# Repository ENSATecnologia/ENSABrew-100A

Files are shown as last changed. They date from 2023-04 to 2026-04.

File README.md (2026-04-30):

# ENSABrew-100A

## PT-BR

Projeto ENSA Tecnologia para controle de brassagem e producao, com firmware ATMEL/Arduino, protocolo serial e logger Node.js.

### Visao geral

O repositorio reune firmware, bibliotecas, protocolo, projeto mecanico, PCB e logger operacional para o equipamento ENSABrew-100A.

### Estrutura

| Caminho | Descricao |
| --- | --- |
| `ENSABrewFirmware/` | Firmware principal e variantes historicas |
| `ENSABrewLibraries/` | Bibliotecas compartilhadas |
| `LoggerBuffaloBrew/` | Logger operacional Node.js |
| `ENSABrewPCB/` | Arquivos de PCB |
| `ENSABrewMechanicalProject/` | Projeto mecanico |
| `Protocol/` e `ENSABrewProtocol/` | Documentacao de protocolo |

### Diretriz de manutencao

`ENSABrew/` e a base ativa de manutencao. `ENSABrewBuffaloBeer/` deve ser tratada como arvore legada/historica, mantida apenas para referencia e comparacao. Novas mudancas devem entrar em `ENSABrew/`, salvo necessidade explicita de suporte a essa variante antiga.

### Estado atual

- A recepcao serial foi corrigida para nao deixar interrupcoes desligadas ao final de um ciclo incompleto de leitura.
- O caminho principal de JSON foi reduzido para `StaticJsonDocument` em vez de `DynamicJsonDocument` nos fluxos mais importantes de serial, APP e resposta remota.
- As chaves de autenticacao e identificadores sensiveis foram movidos para configuracao persistida em EEPROM, com valores de bootstrap definidos no firmware.
- O protocolo serial agora documenta o tamanho maximo do pacote (`DATA_UTIL_SERIAL = 512`) e os campos principais esperados.
- O logger Node.js passou a lidar com framings por linha e limite de buffer, reduzindo erros de leitura parcial.
- As rotinas de display e relogio reduziram copias desnecessarias de `String` nos caminhos mais usados.
- A arvore `ENSABrewBuffaloBeer/` segue documentada como legado, para evitar manutencao dupla.

### Ajustes adicionais que ainda valem

- Reduzir o uso de `String` nas rotinas de receita e nas comparacoes de nome ainda espalhadas pelo firmware.
- Reduzir o uso restante de `String` nas telas de configuracao, edicao de receita e mensagens dinamicas do display.
- Tratar explicitamente pacote incompleto, pacote excedido e erro de autenticacao, sem depender de comportamento implcito do loop.
- Separar melhor codigo do projeto e dependencias vendorizadas, para facilitar manutencao e auditoria.
- Manter o contrato do protocolo centralizado no arquivo `Protocol/protocolo ENSABrew.md`.

### Observacao

Os pontos acima foram inferidos por leitura estatica do codigo e da documentacao, nao por teste em hardware.

### Licenca

Consulte `LICENSE`.

---

## English

ENSA Tecnologia project for brewing/production control, with ATMEL/Arduino firmware, serial protocol and Node.js logger.

### Overview

This repository gathers firmware, libraries, protocol, mechanical project, PCB and the operational logger for the ENSABrew-100A equipment.

### Structure

| Path | Description |
| --- | --- |
| `ENSABrewFirmware/` | Main firmware and historical variants |
| `ENSABrewLibraries/` | Shared libraries |
| `LoggerBuffaloBrew/` | Node.js operational logger |
| `ENSABrewPCB/` | PCB files |
| `ENSABrewMechanicalProject/` | Mechanical project |
| `Protocol/` and `ENSABrewProtocol/` | Protocol documentation |

### Maintenance direction

`ENSABrew/` is the active maintenance base. `ENSABrewBuffaloBeer/` should be treated as a legacy/historical tree, kept only for reference and comparison. New changes should land in `ENSABrew/` unless there is an explicit need to support that older variant.

### Current state

- Serial reception has been corrected so it no longer leaves interrupts disabled after an incomplete read cycle.
- The main JSON path has been reduced to `StaticJsonDocument` instead of `DynamicJsonDocument` in the main serial, APP and remote-reply flows.
- Authentication keys and sensitive identifiers were moved into persisted EEPROM-backed configuration, with firmware bootstrap defaults.
- The serial protocol now documents the maximum packet size (`DATA_UTIL_SERIAL = 512`) and the main expected fields.
- The Node.js logger now handles line-based framing and a bounded buffer to reduce partial-read errors.
- Display and clock routines now avoid unnecessary `String` copies in the most-used paths.
- The `ENSABrewBuffaloBeer/` tree remains documented as legacy to avoid maintaining two active code paths.

### Additional code improvements worth doing

- Reduce `String` usage in recipe routines and in the remaining name comparison helpers in the firmware.
- Reduce the remaining `String` usage in configuration screens, recipe editing and dynamic display messages.
- Handle incomplete packets, oversized packets and authentication failures explicitly instead of relying on loop behavior.
- Separate project code from vendored dependencies more clearly to simplify maintenance and auditability.
- Keep the protocol contract centralized in `Protocol/protocolo ENSABrew.md`.

### Note

The points above were inferred from static code and documentation review, not from hardware testing.

### License

See `LICENSE`.

### Auditoria / Audit
#### PT-BR
- O firmware ja melhorou bastante, mas ainda vale reduzir String restante nas telas, entradas e mensagens dinamicas.
- O contrato do protocolo serial precisa permanecer centralizado e coerente com o logger e o firmware ativo.
- Configuracoes persistidas, limites de buffer e estados legados devem continuar documentados em um unico lugar.
- A prioridade pratica agora e fechar o que ainda gera churn de heap e manter o caminho critico previsivel.
#### EN
- The firmware has improved a lot, but it is still worth reducing the remaining String usage in screens, inputs and dynamic messages.
- The serial protocol contract must stay centralized and aligned with the logger and the active firmware.
- Persisted configuration, buffer limits and legacy states should continue to be documented in one place.
- The practical priority now is to close the remaining heap churn and keep the critical path predictable.

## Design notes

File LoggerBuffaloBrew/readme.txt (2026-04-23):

-> Descrição do dado: (NOME DA RECEITA) | (RAMPA/SETPOINT) | (N° RAMPA/SETPOINT) | (TEMP. SENSOR) | (TEMP. SETPOINT) | (TEMPO ATUAL) | (ESTADO RELÉ)
	
	- (NOME DA RECEITA): Nome da receita atual;
	
	- (RAMPA/SETPOINT): Se refere a etapa em si, em qual delas está, ou RAMPA (subindo a temperatura) ou SETPOINT (contando tempo e mantendo a temperatura);
	
	- (N° RAMPA/SETPOINT): Se refere ao número/ID da RAMPA ou do SETPOINT, ambos serão os mesmos;

	- (TEMP. SENSOR): Temperatura atual do SENSOR;
	
	- (TEMP. SETPOINT): Temperatura atual do SETPOINT (será fixa na contagem de tempo);

	- (TEMPO ATUAL): tempo total do SETPOINT em questão (em minutos). Enquanto estiver em RAMPA, se mantém travado até chegar ao SETPOINT e chegando ao mesmo, faz uma contagem decrescente;

	- (ESTADO RELÉ): Estado atual do relé: (1) acionado | (0) desacionado

* OBSERVAÇÃO:
	
	-> Caso queira alterar a PORTA de conexão com o servidor, acesse o arquivo 'conectionPort.js' e altere diretamente o valor;

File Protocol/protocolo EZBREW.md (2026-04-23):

#### Cabeçalho padrão ENSA Tecnologia

	Cabeçalhos de equipamentos ENSA Tecnologia
		4E

	Cabeçalhos de segmento
		0001 - Postos de combustíveis
		0002 - Módulos IoT voltado ao condomínio

	Identificador de módulo
		ZZZZZZZZZ é 09 bytes, sendo [a-zA-Z0-9]

	Tipo do módulo
		D001 - Portas i/o Raspberry PI3
		D002 - Módulo 433Mhz TCP/IP v4
		D003 - Módulo 433Mhz TCP/IP v4 OFFLINE
		D004 - Módulo Wiegand TCP/IP v4
		D005 - Módulo Wiegand TCP/IP v4 OFFLINE
		D006 - Módulo de leitura de bombas 

#### * Observação: Protocolo baseado em Json

	  Exemplo - início do cabeçalho:

				{"header":"4E",
				 "product":"0002",
				 "type":"D002",
				 "id":"1020ABC01",
				 "typeCmd":"...",
				 "cmd":"...",...}

#### CC - Cabeçalho de comando

###### Faixa de cabeçalhos CC

| Nome | Tipo ("typeCmd") | Faixa ("cmd")|
|---|---|---|
| Conexão | CC 	 	 | 00 	 |
| Receitas | CC 	 	 | 01 à 04 |
| Teclado Virtual | CC 	 	 | 05 |
| Configurações | CC 	 	 | 06 à 09 |
| Funções administrativas| CC 	 	 | 0A à 0E |
 
###### Conexão
	
	00 - Subcabeçalho para confirmar a conexão:
      
	- Exemplo: do APP para o equipamento
     
			{"header":"4E",
			 "product":"0002",
			 "type":"D002",
			 "id":"1020ABC01",
			 "typeCmd":"CC",
			 "cmd":"00"}

	- Exemplo: do equipamento para o APP  
     
			{"header":"4E",
			 "product":"0002",
			 "type":"D002",
			 "id":"1020ABC01",
			 "typeCmd":"CC",
			 "cmd":"00",
			 "connection:":"ack"}

###### Receitas

	01 - Subcabeçalho para CRIAR uma receita:
     
	-Parâmetros:
     
		-> Nome da receita:                            
			
			"receita":["nome da receita"],
     
		-> Quantidade de patamares e suas temperaturas: (em °C)
			
			"tempPatamar":[50],
       
	*Obs: o número de patamares será definido de acordo com a quantidade de temperaturas que forem definidas dentro dos colchetes.
     
		-> Tempo dos patamares: (em minutos) 
			
			"minPatamar":[5],
          
	*Obs: a quantidade de tempo dentro dos colchetes deve corresponder à quantidade de patamares definidos anteriormente.
      
		-> Temperatura de fervura:  (em °C)
			
			"tempFervura":100,
      
		-> Tempo em fervura: (em minutos)
			
			"minFervura":3,
     
		-> Quantidade e nomes das adições:	  
			
			"nomeAdicao":["Nome adicao"],    
       
	*Obs: o número de adições será definido de acordo com a quantidade de nomes que forem definidos dentro dos colchetes.
     
		-> Quantidade de adição: (em gramas)
			
			"gramasAdicao":[100],
     
    *Obs: a quantidade de adição dentro dos colchetes deve corresponder àquantidade de adições definidos anteriormente.
     
		-> Tempo de cada adição: (em minutos)
			
			"minAdicao":[5],
     
    *Obs: a quantidade de tempo dentro dos colchetes deve corresponder àquantidade de adições definidos anteriormente.
     
		-> Quantidade e nome dos Whirpools: 
			
			"nomeWhirpool":["Nome do Whirpool"],
     
    *Obs: o número de whirpools será definido de acordo com a quantidade de nomes que forem definidos dentro dos colchetes.  
     
		-> Tempo em cada Whirpool: (em minutos)
			
			"minWhirpool":[10],
     
    *Obs: a quantidade de tempo dentro dos colchetes deve corresponder àquantidade de whirpools definidos anteriormente.
     
		-> Tempo de descanso: (em minutos)
			
			"minDescanso":30}
     
	- Exemplo:
     
			{"header":"4E",
			 "product":"0002",
			 "type":"D002",
			 "id":"1020ABC01",
			 "typeCmd":"CC",
			 "cmd":"01",
			 "receita":[1,"Receita Exemplo"],
			 "tempPatamar":[75],
			 "minPatamar":[15],
			 "tempFervura":150,
			 "minFervura":10,
			 "nomeAdicao":["Adicao Exemplo"],
			 "gramasAdicao":[500],
			 "minAdicao":[2],
			 "nomeWhirpool":["Whirpool Exemplo"],
			 "minWhirpool":[20],
			 "minDescanso":15}

--------------------------------------------------------------------------
	
	02 - Subcabeçalho para EDITAR uma receita:
	 
	*Obs: as regras de criação valem para edição.   
	  
	-Parâmetros:
     
		-> Nome e número da receita: 
			
			..."receita":[1, "nome da receita editado"],
	     
		-> Quantidade de patamares e suas temperaturas: (em °C)
		   	
		   	"tempPatamar":[25],
	      
		-> Tempo dos patamares: (em minutos)  
		   	
		   	"minPatamar":[10],
	          
		-> Temperatura de fervura:  (em °C)    
		   	
		   	"tempFervura":200,
	     
		-> Tempo em fervura: (em minutos)   
		   	
		   	"minFervura":5,
	     
		-> Quantidade e nomes das adições:  
		   	
		   	"nomeAdicao":["Nome adicao editado"],    
	     
		-> Quantidade de adição: (em gramas)
		   	
		   	"gramasAdicao":[250],
	     
		-> Tempo de cada adição: (em minutos)
		   	
		   	"minAdicao":[20],
	     
		-> Quantidade e nome dos Whirpools: 
		   	
		   	"nomeWhirpool":["Nome do Whirpool editado"],
	     
		-> Tempo em cada Whirpool: (em minutos)
		   	
		   	"minWhirpool":[9],
	     
		-> Tempo de descanso: (em minutos)
		   	
		   	"minDescanso":30}
     
	- Exemplo:
     
			{"header":"4E",
			 "product":"0002",
			 "type":"D002",
			 "id":"1020ABC01",
			 "typeCmd":"CC",
			 "cmd":"02",
			 "receita":[1,"Receita Exemplo"],
			 "tempPatamar":[25],
			 "minPatamar":[10],
			 "tempFervura":80,
			 "minFervura":8,
			 "nomeAdicao":["Adicao Exemplo"],
			 "gramasAdicao":[250],
			 "minAdicao":[5],
			 "nomeWhirpool":["Whirpool Exemplo"],
			 "minWhirpool":[12],
			 "minDescanso":25}

--------------------------------------------------------------------------
	
	03 - Subcabeçalho para APAGAR uma receita:
      
		- Necessário apenas o número da receita à ser apagada: 
			
			..."receita":[1, ""]}	
     
	- Exemplo:
     
			{"header":"4E",
			 "product":"0002",
			 "type":"D002",
			 "id":"1020ABC01",
			 "typeCmd":"CC",
			 "cmd":"03",
			 "receita":[1,""]}

--------------------------------------------------------------------------

	04 - Subcabeçalho para BRASSAR uma receita:
      
		- Necessário apenas o número da receita à ser brassada: 
			
			..."receita":[1, ""]}
     
	- Exemplo:
     
			{"header":"4E",
			 "product":"0002",
			 "type":"D002",
			 "id":"1020ABC01",
			 "typeCmd":"CC",
			 "cmd":"04",
			 "receita":[1,""]}	

###### Teclado Virtual

	05 - Subcabeçalho para uso do "teclado virtual":
      
	- As teclas são definidas por seus respectivos nomes:
     
		-> UP
		-> DOWN
		-> LEFT
		-> RIGHT
		-> ENTER
		-> ESC
     
    	- Necessário apenas o nome da tecla à ser "pressionada":
        
    		..."vKey":"UP"}
     
	- Exemplo:
     
			{"header":"4E",
			 "product":"0002",
			 "type":"D002",
			 "id":"1020ABC01",
			 "typeCmd":"CC",
			 "cmd":"05",
			 "vKey":"UP"}

###### Configurações

	06 - Subcabeçalho para configurar o máximo de patamares:
     
    	- Necessário apenas o máximo de patamares desejado:
     
			..."maxPatamar":"10"}
     
	- Exemplo:
     
			{"header":"4E",
			 "product":"0002",
			 "type":"D002",
			 "id":"1020ABC01",
			 "typeCmd":"CC",
			 "cmd":"06",
			 "maxPatamar":"10"}

--------------------------------------------------------------------------

	07 - Subcabeçalho para configurar os graus por minuto:
     
    	- Necessário apenas o grau por minuto desejado:
     
			..."grauPorMinuto":"1.5"}
     
	- Exemplo:
     
			{"header":"4E",
			 "product":"0002",
			 "type":"D002",
			 "id":"1020ABC01",
			 "typeCmd":"CC",
			 "cmd":"07",
			 "grauPorMinuto":"1.5"}

--------------------------------------------------------------------------

	08 - Subcabeçalho para configurar o PWM para Setpoint:
     
    	- Necessário apenas o PWM desejado:
     
			..."setPWM":"75"}
     
	- Exemplo:
     
			{"header":"4E",
			 "product":"0002",
			 "type":"D002",
			 "id":"1020ABC01",
			 "typeCmd":"CC",
			 "cmd":"08",
			 "setPWM":"75"}

--------------------------------------------------------------------------

	09 - Subcabeçalho para configurar Data e Hora:
     
    	- Configurar os segundos:
     
			..."segundos":"00",
     
    	- Configurar os minutos:
     
			"minutos":"30",
     
    	- Configurar as horas:
     
			"horas":"09",
     
    	- Configurar o dia da semana: 
      
    	(1-SEG)(2-TER)(3-QUA)(4-QUI)(5-SEX)(6-SAB)(7-DOM)
     
			"diaDaSemana":"2",	
     
    	- Configurar o dia do mês:
     
			"diaDoMes":"15",
     
    	- Configurar o mês:
     
			"mes":"01",
     
    	- Configurar o ano:
     
			"ano":"2019"}
        
	- Exemplo:
     
			{"header":"4E",
			 "product":"0002",
			 "type":"D002",
			 "id":"1020ABC01",
			 "typeCmd":"CC",
			 "cmd":"05",
			 "segundos":"00",
			 "minutos":"30",
			 "horas":"09",
			 "diaDaSemana":"2",	
			 "diaDoMes":"15",
			 "mes":"01",
			 "ano":"2019"}

	--------------------------------------------------------------------------

	10 - Subcabeçalho para configurar o PID:
     
    	- Configurar o status: 00 - desabilitado | 01 - habilitado
     
			..."status":"01",
     
    	- Configurar kp:
     
			"kp":"1.5",
     
    	- Configurar ki:
     
			"ki":"2.5",
     
    	- Configurar kd:
     
			"kd":"3.5",
        
	- Exemplo:
     
			{"header":"4E",
			 "product":"0002",
			 "type":"D002",
			 "id":"1020ABC01",
			 "typeCmd":"CC",
			 "cmd":"10",
			 "status":"01",
			 "kp":"1.5",
			 "ki":"2.5",
			 "kd":"3.5"}

###### Funções Administrativas

	0A - Subcabeçalho para limpar a EEPROM:
     
    	- Necessário apenas o comando:
       
    		..."cmd":"0A"} 
     
	- Exemplo:
     
			{"header":"4E",
			 "product":"0002",
			 "type":"D002",
			 "id":"1020ABC01",
			 "typeCmd":"CC",
			 "cmd":"0A"}

	0B - Subcabeçalho para alterar o tempo de envio de dados da brassagem:
     
    - Necessário apenas o tempo (em segundos) desejado:
     
			..."setTime":"1"}
       
	- Exemplo:
     
			{"header":"4E",
			 "product":"0002",
			 "type":"D002",
			 "id":"1020ABC01",
			 "typeCmd":"CC",
			 "cmd":"0B",
			 "setTime":"5"}

	0C - Controle dos solenóides
     
    - Necessário definir o solenóide em que será feito o controle (1 (00) ou 2 (01))
     
			..."solenoid":"00"} 

	- Necessário definir a ação - acionar (01) ou desacionar (00)
     
			..."action":"01"}      

    - Necessário definir o tempo:
     
			..."operatingTime":"10"}

	- Necessário definir o tipo do temporizador (mili segundos (00), segundos (01) ou minutos (02)):
     
			..."timerType":"01"}

	*OBS: para acionamento sem temporização, colocar 0 em ambos campos acima

	- Exemplo: acionar o solenóide 1 por 10 segundos
     
			{"header":"4E",
			 "product":"0002",
			 "type":"D002",
			 "id":"1020ABC01",
			 "typeCmd":"CC",
			 "cmd":"0C",
			 "solenoid":"00",
			 "action":"01",
			 "operatingTime":"10",
			 "timerType":"01"}

	0D - Subcabeçalho para alterar o fator de calibração:
     
    - Caso queira inserir diretamento o fator de calibração, coloque algum dado no campo "calFactor" e zera o campo realLiters":
     		
     		..."calFactor":"4.5"}
     		..."realLiters":"0.0"}

    - Caso queira que o equipamento calcule o novo fator de calibrãção à partir dos litros reais inseridos, deixe o campo "calFactor" zerado e preencha o campo "realLiters":

    		..."calFactor":"0.0"}
			..."realLiters":"5.5"}
       
	- Exemplo 1: inserindo direto o fator 
     
			{"header":"4E",
			 "product":"0002",
			 "type":"D002",
			 "id":"1020ABC01",
			 "typeCmd":"CC",
			 "cmd":"0D",
			 "calFactor":"4.5",
			 "realLiters":"0.0"}

	- Exemplo 2: cálculo automático do fator
     
			{"header":"4E",
			 "product":"0002",
			 "type":"D002",
			 "id":"1020ABC01",
			 "typeCmd":"CC",
			 "cmd":"0D",
			 "calFactor":"0.0",
			 "realLiters":"5.5"}

	0E - Subcabeçalho para configurar o envio da leitura AC:
     
    - Para desabilitar a leitura AC, colocar "0" no campo "time"
     		
     		..."time":"0"}
      
    - Para configurar um tempo e habilitar o envio nesse tempo, basta colocar um valor entre 1 e 255 (segundos) no campo "time"
      
    		..."time":"10"}

    - Exemplo:  
     
			{"header":"4E",
			 "product":"0002",
			 "type":"D002",
			 "id":"1020ABC01",
			 "typeCmd":"CC",
			 "cmd":"0E",
			 "time":"10"}

	0F - Subcabeçalho para configurar o envio da temperatura:
     
    - Para desabilitar o envio, colocar "0" no campo "time"
     		
     		..."time":"0"}
      
    - Para configurar um tempo e habilitar o envio nesse tempo, basta colocar um valor entre 1 e 255 (segundos) no campo "time"
      
    		..."time":"10"}
    			
    - Exemplo:  
     
			{"header":"4E",
			 "product":"0002",
			 "type":"D002",
			 "id":"1020ABC01",
			 "typeCmd":"CC",
			 "cmd":"0F",
			 "time":"10"}

#### FF - Cabeçalho de solicitação

###### Faixa de cabeçalhos FF

| Nome | Tipo ("typeCmd") | Faixa ("cmd")|
|---|---|---|
| Receitas | FF 	 	 | 01 |
| Configurações | FF | 02, 0D à FF  |
| Tela atual			 | FF				| 03		 |

###### Receitas

	01 - Subcabeçalho para solicitar uma receita:
      
		- Necessário apenas o número da receita à ser solicitada: 
			
			..."receita":[1, ""]}	
     
	- Exemplo:
     
			{"header":"4E",
			 "product":"0002",
			 "type":"D002",
			 "id":"1020ABC01",
			 "typeCmd":"FF",
			 "cmd":"01",
			 "receita":[1,""]}

###### Configurações

	02 - Subcabeçalho para solicitar as configurações do dispositivo:	
     
	- Exemplo de solicitação:
     
			{"header":"4E",
			 "product":"0002",
			 "type":"D002",
			 "id":"1020ABC01",
			 "typeCmd":"FF",
			 "cmd":"02"}
     
	- Exemplo de resposta:
      
			{"header":"4E",
			 "product":"0002",
			 "type":"D002",
			 "id":"1020ABC01",
			 "typeCmd":"FF",
			 "cmd":"02",
			 "qtdeMaxPatamar":"7",
			 "pwmSetpoint":"95",
			 "tempoEnvioBrassagem":"1",
			 "grauPorMinuto":"1.0",
			 "code":["A2"]}

	0D - Subcabeçalho para solicitar o fator de calibração:
     
	- Exemplo:
     
			{"header":"4E",
			 "product":"0002",
			 "type":"D002",
			 "typeCmd":"FF",
			 "cmd":"0D",
			 "calFactor":"4.5",
			 "code":["A2"]}

	0E - Subcabeçalho para solicitar o tempo de envio da leitura AC:
     
	- Exemplo:
     
			{"header":"4E",
			 "product":"0002",
			 "type":"D002",
			 "typeCmd":"FF",
			 "cmd":"0E",
			 "time":"10",
			 "code":["A2"]}

	0F - Subcabeçalho para solicitar o tempo de envio da temperatura:
     
	- Exemplo:
     
			{"header":"4E",
			 "product":"0002",
			 "type":"D002",
			 "typeCmd":"FF",
			 "cmd":"0F",
			 "time":"10",
			 "code":["A2"]}

	10 - Subcabeçalho para solicitar a configuração do PID:
			
	- Exemplo:
     
			{"header":"4E",
			 "product":"0002",
			 "type":"D002",
			 "typeCmd":"FF",
			 "cmd":"10",
			 "status":"01",
			 "kp":"1.5",
			 "ki":"2.5",
			 "kd":"3.5",
			 "code":["A2"]}

	FF - Subcabeçalho para solicitar o número de série/Id:
     
	- Exemplo:
     
			{"header":"4E",
			 "product":"0002",
			 "type":"D002",
			 "typeCmd":"FF",
			 "cmd":"FF"}

###### Receitas

	03 - Subcabeçalho para solicitar a tela atual:	
     
	- Exemplo:
     
			{"header":"4E",
			 "product":"0002",
			 "type":"D002",
			 "id":"1020ABC01",
			 "typeCmd":"FF",
			 "cmd":"01",
			 "tela":"Menu Principal",
			 "opcao":"Escolhe receita"}

#### Respostas à comandos e solicitações

###### Tabela de respostas

| Código | Descrição |
|---|---|
| A1 | Código de comando aceito e deserealização completa |
| A2 | Código de solicitação aceita |
| E1 | Código de entrada serial incompleta |
| E2 | Código de entrada inválida |
| E3 | Código de memória insuficiente |
| E4 | Código de comando não suportado | 
| E5 | Código de "Too Deep" |
| E6 | Código de falha na deserealização |
| E7 | Código de cabeçalho desconhecido |
| E8 | Código de comando desconhecido |
| E9 | Código de solicitação desconhecida |
| E10 | Código de memória cheia |
| E11 | Código de memória vazia |
| E12 | Código de receita inexistente |
| E13 | Código de nome de receita já existente |
| E14 | Código de brassagem: aguardar o fim para comandos  |
| E15 | Código de número de série inválido					|

#### Dados enviados por serial durante brassagem

* À cada 1 segundo, durante a brassagem, o equipamento envia via serial os dados da brassagem.

-> Patamares:
	                        	        
	- Exemplo:
            
			{"header":"4E",
			 "product":"0002",
			 "type":"D002",
			 "typeCmd":"FF",
			 "cmd":2,
			 "temp":25,
			 "status":"PATAMAR",
			 "pwm":80,
			 "speed":100,
			 "patamar":1,
			 "tempo":60, (segundos)
			 "cmd":"A1"}

-> Fervura/adições:
	                        	        
	- Exemplo:
            
			{"header":"4E",
			 "product":"0002",
			 "type":"D002",
			 "typeCmd":"FF",
			 "cmd":2,
			 "restante":5000,       (tempo restante, segundos)
			 "proximo":60,          (tempo adição, segundos)
			 "nAdicao":1,
			 "tempo":60,            (segundos)
			 "cmd":"A1"}

-> Whirpool:

	- Exemplo:
            
			{"header":"4E",
			 "product":"0002",
			 "type":"D002",
			 "typeCmd":"FF",
			 "cmd":2,
			 "restante":5000,       (tempo restante, segundos)
			 "proximo":60,          (tempo whirpool, segundos)
			 "nWhirlpool":1,
			 "tempo":60,            (segundos)
			 "cmd":"A1"}

-> Descanso:

	- Exemplo:
            
			{"header":"4E",
			 "product":"0002",
			 "type":"D002",
			 "typeCmd":"FF",
			 "cmd":2,
			 "restante":5000,       (tempo restante, segundos)
			 "proximo":60,          (tempo descanso, segundos)
			 "nDescanso":1,
			 "tempo":60,            (segundos)
			 "cmd":"A1"}

#### EE - Cabeçalho de evento

###### Faixa de cabeçalhos EE

| Nome | Tipo ("typeCmd") | Faixa ("cmd")|
|---|---|---|
| Keep Alive			 | EE 				| 00		 |
| Entradas digitais | EE 	 	 | 01 	 |
| Leitura da temperatura | EE 	 	 | 02 |
| Fluxo			 | EE 	 	 | 03 |
| Leitura AC	 | EE 	 	 | 04 |

###### Keep Alive

	00 - Subcabeçalho para evento de keep alive:	

	- Exemplo: 
     
			{"header":"4E",
			 "product":"0002",
			 "type":"D002",
			 "id":"1020ABC01",
			 "typeCmd":"EE",
			 "cmd":"00"}

	*OBS: o dado enviado será exatamente igual, tanto de APP -> equipamento quanto de equipamento -> APP

###### Entradas digitais

	01 - Subcabeçalho para evento de leitura da porta digital:	
		
	- Exemplo:
     
			{"header":"4E",
			 "product":"0002",
			 "type":"D002",
			 "id":"1020ABC01",
			 "typeCmd":"EE",
			 "cmd":"01",
			 "port":"02",
			 "state":"HIGH"}

	- Temos duas portas, logo "entrada - port" varia entre 01 e 02;
	- Temos dois estados, logo "estado - state" varia entre LOW e HIGH

###### Leitura da temperatura

	02 - Subcabeçalho para evento de leitura de temperatura:	
			
	- Exemplo:
     
			{"header":"4E",
			 "product":"0002",
			 "type":"D002",
			 "id":"1020ABC01",
			 "typeCmd":"EE",
			 "cmd":"02",
			 "temp":"25.0"}

###### Fluxo

	03 - Subcabeçalho para evento de leitura de fluxo:	

	- Exemplo:
     
			{"header":"4E",
			 "product":"0002",
			 "type":"D002",
			 "id":"1020ABC01",
			 "typeCmd":"EE",
			 "cmd":"03",
			 "flow":"0.00",
			 "liters":"0.00"}

###### Leitura AC

	04 - Subcabeçalho para evento de leitura AC: 00 - não presente | 01 - presente	

	- Exemplo:
     
			{"header":"4E",
			 "product":"0002",
			 "type":"D002",
			 "id":"1020ABC01",
			 "typeCmd":"EE",
			 "cmd":"04",
			 "ac":"01"}

#### Envio das telas atuais do Hardware para o app

* À cada mudança de tela, o equipamento enviará a tela atual para o app.
	                        	        
	- Exemplo:
            
			{"header":"4E",
       		 "product":"0002",  
			 "type":"D002",                      
			 "tela": "Menu Principal"}

#### Tabela de descrição e especificação das telas

| Tela | Descrição 										 |
|---|---|
| Stand by | Tela de apresentação, descanso						 |
| Menu Principal | Escolher receita, criar receita, Adicionar água, Configuração|
| Menu receitas | Receitas presentes na controladora 		 |
| Menu da receita | Brassar, editar ou apagar a receita selecionada				 | 
| Criar receita | Parâmetros de criação de uma nova receita					 |
| Editar receitas | Parâmetros de edição de uma receita	existente				 |
| Configurar data e hora  | Configurar os parâmetros de data e hora do dispositivo		 |
| Adicionar água | Adição de água automática, seleção da quantidade em litros	 |

#### Tabelas de máximos, mínimos e defaults dos parâmetros

| Patamares | Máximo | Mínimo | Default |
|---|---|---|---|
| Quantidade | 10 | 1 | 2 |
| Tempo (min) |  300 | 0 | 5 |
| Temperatura |  100 | 1 | 25 |

| Fervura | Máximo | Mínimo | Default |
|---|---|---|---|
| Temperatura |  200 | 25 | 100 |
| Tempo (min) |  500 | 1 | 60 |

| Adições | Máximo | Mínimo | Default |
|---|---|---|---|
| Total | 5 | 0 | 1 |
| Quantidade(g) |  500 | 1 | 10 |
| Tempo (min) | 60 | 0 | 15 |

| Whirpool | Máximo | Mínimo | Default |
|---|---|---|---|
| Total | 2 | 0 | 2 |
| Tempo (min) | 60 | 0 | 10 |

| Descanso | Máximo | Mínimo | Default |
|---|---|---|---|
| Total | 1 | 0 | 1 |
| Tempo (min) | 60 | 0 | 10 |

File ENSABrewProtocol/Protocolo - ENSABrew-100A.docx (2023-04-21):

DO PROTOCOLO:

Para cada comando enviado, tem-se o seguinte formato:

CABEÇALHO + TIPO DE COMANDO + COMANDO + DADOS (APLICÁVEL)

Para cada comando recebido, tem-se o seguinte formato:

CABEÇALHO + TIPO DE COMANDO + COMANDO + DADOS (APLICÁVEL) + CODE

CABEÇALHO/AUTENTICAÇÃO (IMUTÁVEL EXTERNAMENTE/PELO APP - FIXO NO CÓDIGO C/C++):

{

"header":"4E",

"product":"0002",

"type":"D002",

"id":"1020ABC01"

}

TIPO DE COMANDOS - "typeCmd":

Comandos de atribuição - SET

{

"typeCmd":"CC",

}

Comandos de solicitação - GET

{

"typeCmd":"FF",

}

COMANDOS - "cmd":"1

Quando "CC" varia de 1 a 4: CRIAR/EDITAR/APAGAR/BRASSAR

{

"cmd":"4",

}

Quando "FF" varia de 1 a 1: SOLICITAR RECEITA

{

"cmd":"1",

}

DADOS:

Quando "CC", é a receita efetiva;

Quando "FF, apenas o índice da receita;

{

"receita":[

1,

"ENSA"

],

"tempPatamar":[

25,

35,

55

],

"minPatamar":[

100,

200,

300

],

"tempFervura":100,

"minFervura":200,

"nomeAdicao":[

"LIMAO",

"ABACAXI",

"CEREJA"

],

"gramasAdicao":[

100,

150,

200

],

"minAdicao":[

60,

30,

20

],

"nomeWhirlpool":[

"LENTO",

"RAPIDO"

],

"minWhirlpool":[

20,

10

],

"minDescanso":15

}

EXEMPLO PARA CRIAR RECEITA - CC1:

{

"header":"4E",

"product":"0002",

"type":"D002",

"id":"1020ABC01",

"typeCmd":"CC",

"cmd":"1",

"receita":[

1,

"ENSA"

],

"tempPatamar":[

25,

35,

55

],

"minPatamar":[

100,

200,

300

],

"tempFervura":100,

"minFervura":200,

"nomeAdicao":[

"LIMAO",

"ABACAXI",

"CEREJA"

],

"gramasAdicao":[

100,

150,

200

],

"minAdicao":[

60,

30,

20

],

"nomeWhirlpool":[

"LENTO",

"RAPIDO"

],

"minWhirlpool":[

20,

10

],

"minDescanso":15

}

EXEMPLO PARA EDITAR RECEITA - CC2:

{

"header":"4E",

"product":"0002",

"type":"D002",

"id":"1020ABC01",

"typeCmd":"CC",

"cmd":"2",

"receita":[

1,

"TECNOLOGIA"

],

"tempPatamar":[

25,

35,

55

],

"minPatamar":[

10,

48,

82

],

"tempFervura":120,

"minFervura":50,

"nomeAdicao":[

"CASCA",

"ABACAXI",

"CAJU"

],

"gramasAdicao":[

30,

15,

20

],

"minAdicao":[

3,

4,

2

],

"nomeWhirlpool":[

"LOW",

"FAST"

],

"minWhirlpool":[

1,

2

],

"minDescanso":5

}

EXEMPLO PARA APAGAR RECEITA - CC3:

{

"header":"4E",

"product":"0002",

"type":"D002",

"id":"1020ABC01",

"typeCmd":"CC",

"cmd":"3",

"receita":[

1,

""

]

}

EXEMPLO PARA REALIZAR BRASSAGEM - CC4:

{

"header":"4E",

"product":"0002",

"type":"D002",

"id":"1020ABC01",

"typeCmd":"CC",

"cmd":"4",

"receita":[

1,

""

]

}

EXEMPLO PARA SOLICITAR RECEITA - FF1:

{

"header":"4E",

"product":"0002",

"type":"D002",

"id":"1020ABC01",

"typeCmd":"FF",

"cmd":"1",

"receita":[

1,

""

]

}

DOS CÓDIGOS DE ERRO:

A1 – Data “CC” Deserialization succeeded

A2 – Data “FF” Deserialization succeeded

E1 – Incomplete Input

E2 – Invalid input

E3 – Not enough memory

E4 – Not Supported

E5 – Too Deep

E6 – Deserialization failed

E7 – Type Command: Unknown

E8 – Request Command: Unknown

E9 – Reply Command: Unknown

E10 – Memory full

E11 – Empty Memory

DOS EXEMPLO DE COMANDO RECEBIDO – RECEITA EDITADA COM SUCESSO:

{

"header":"4E",

"product":"0002",

"type":"D002",

"id":"1020ABC01",

"typeCmd":"CC",

"cmd":"2",

"code":[

A1,

]

}

DOS VALORES DA BRASSAGEM EM REAL-TIME:

Quando se tem o início da brassagem - CC4, o equipamento fica mandando eventos (a cada 1s) para podermos fazer o gráfico de brassagem, as variáveis mais importantes são “temp” – temperatura e “tempo” – tempo:

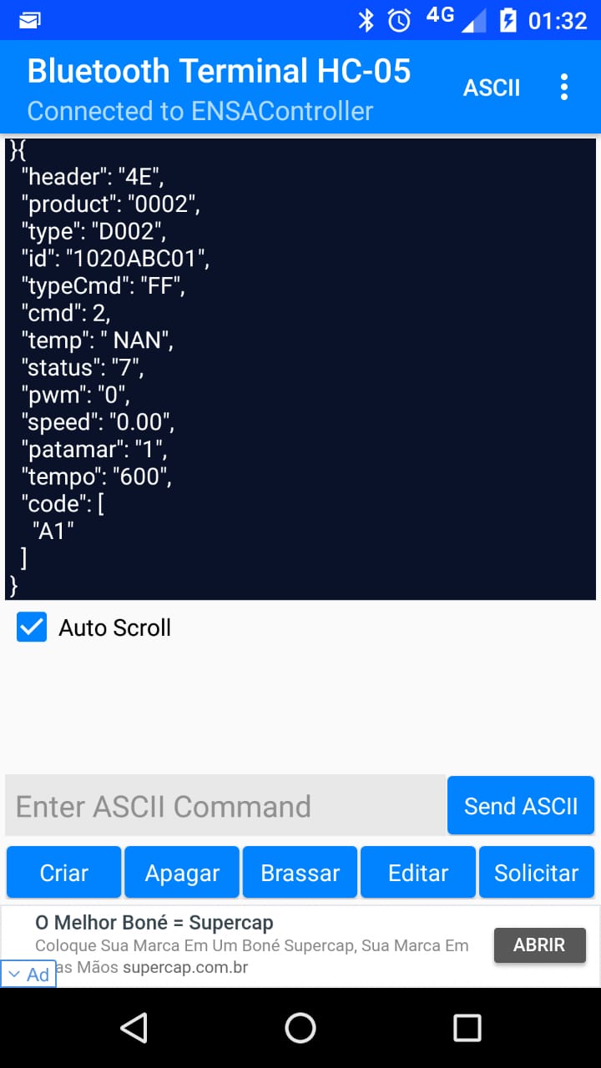
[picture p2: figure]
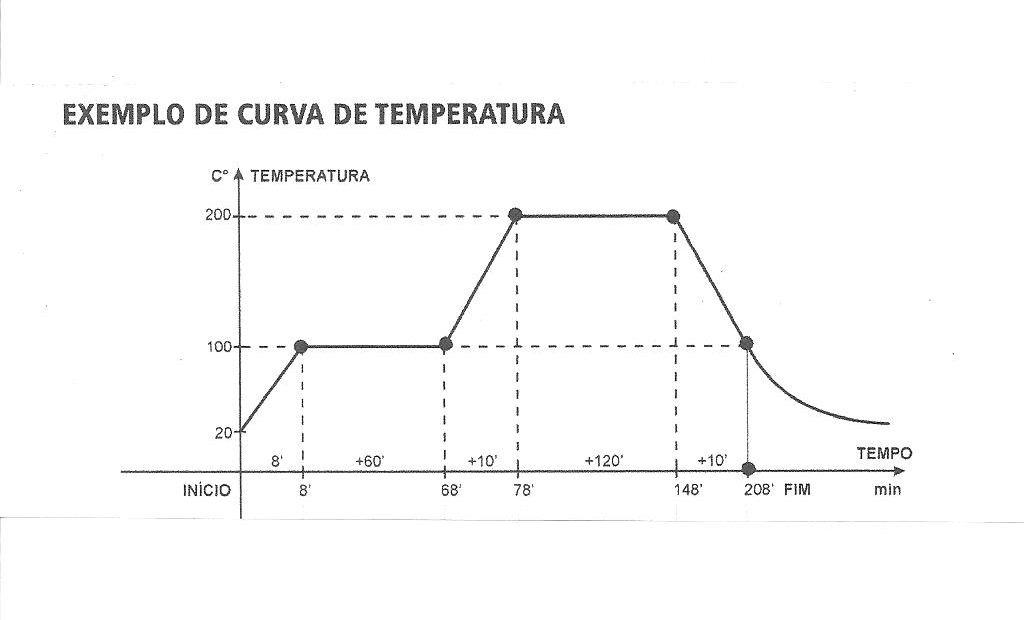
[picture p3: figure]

DOS VALORES MÁXIMOS E MÍNIMOS DAS VARIÁVEIS:

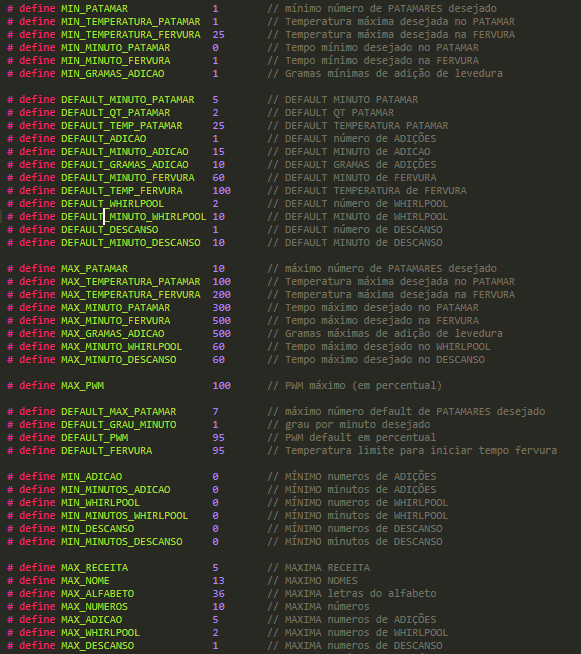
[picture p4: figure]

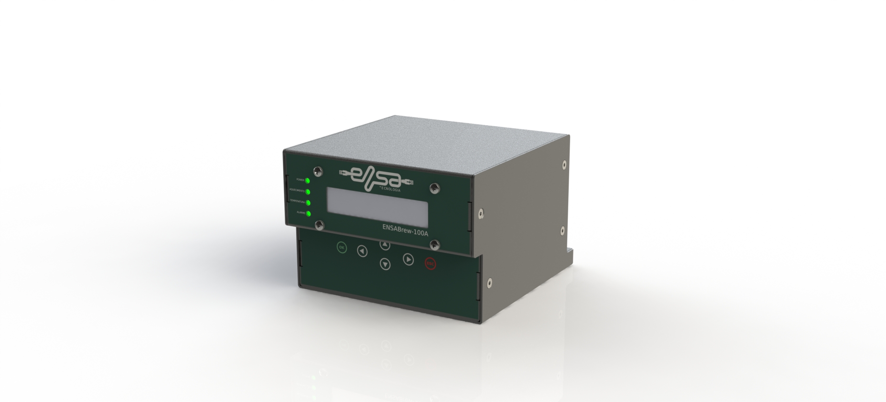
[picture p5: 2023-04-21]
ENSABrewMechanicalProject/Version 2.0/Render/Front.JPG

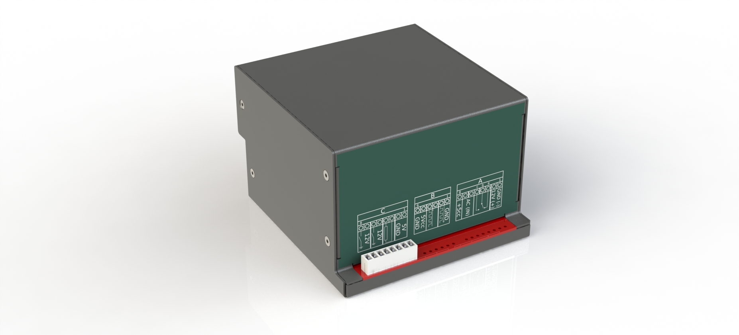
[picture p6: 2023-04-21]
ENSABrewMechanicalProject/Version 2.0/Render/Back.JPG

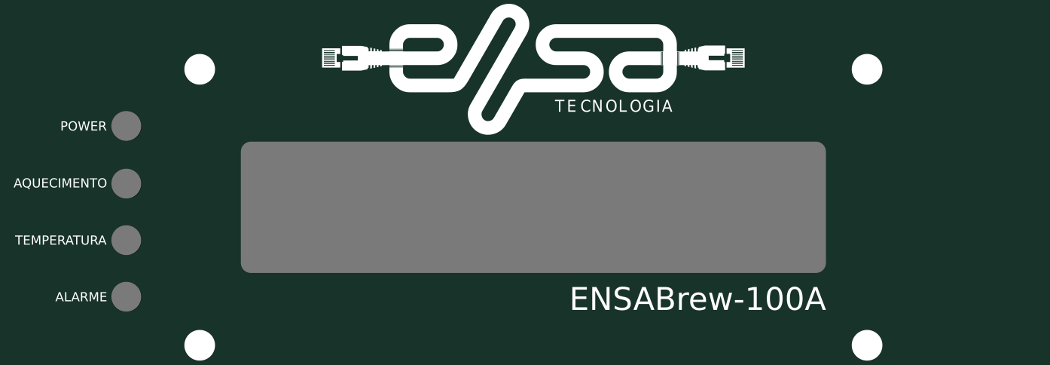
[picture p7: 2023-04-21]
ENSABrewMechanicalProject/Version 2.0/Adesivo/AdesivoDisplay_V2.png

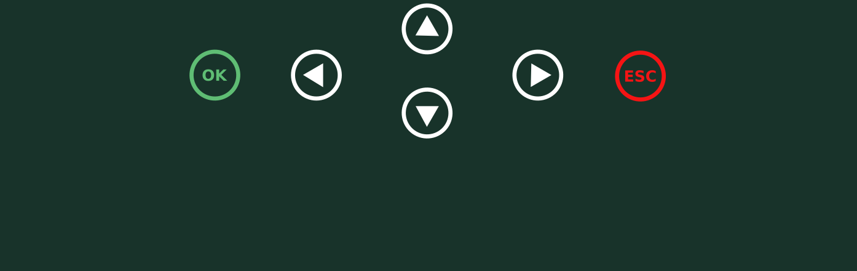
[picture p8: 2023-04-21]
ENSABrewMechanicalProject/Version 2.0/Adesivo/AdesivoTeclado_V2.png

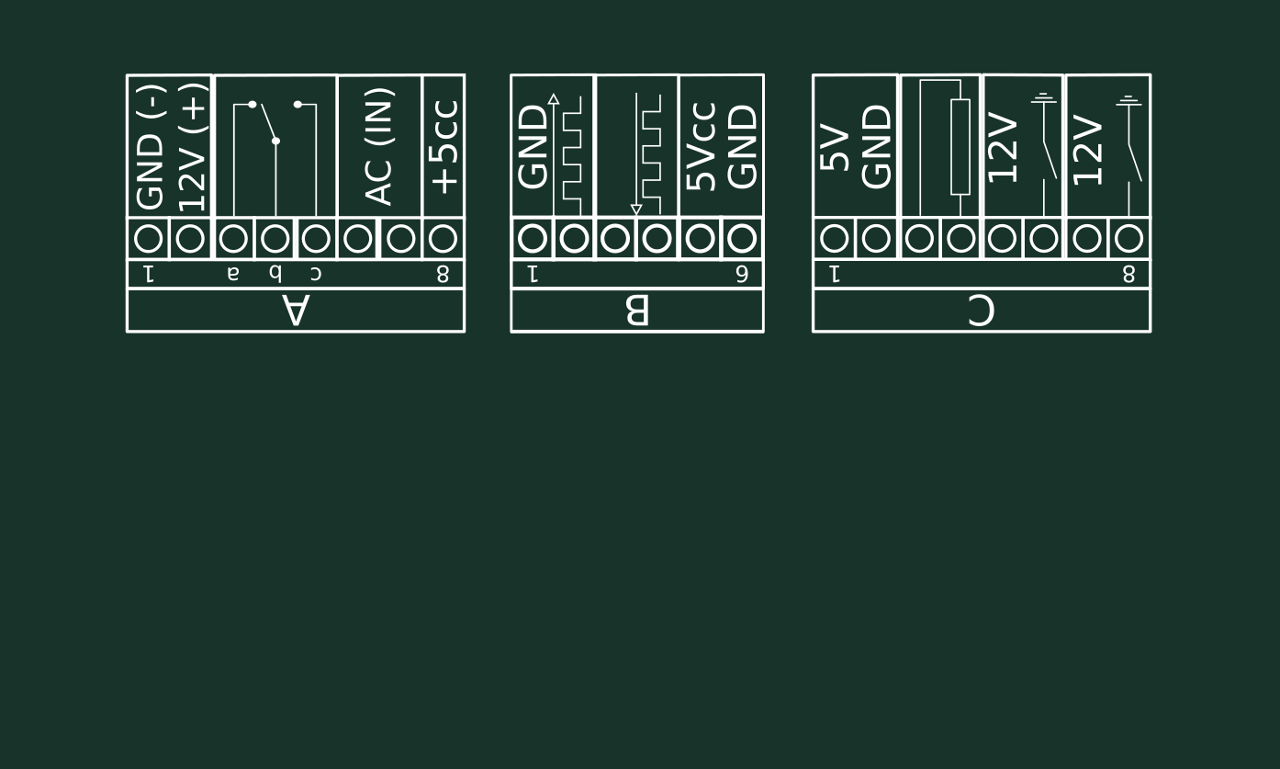
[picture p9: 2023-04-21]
ENSABrewMechanicalProject/Version 2.0/Adesivo/AdesivoConectores_V2.png

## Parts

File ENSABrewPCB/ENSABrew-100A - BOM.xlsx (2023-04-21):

Count | Component Name | Código ENSA | Reference | Pattern Name | Value | Description | Links | Unitary Value | Total Value
1 | Passive Buzzer Piezo Speaker | 023-002 | SG1 | HXD - Passive Buzzer Piezo Speaker 5V/10mm | HXD - 5V/10mm | 5V Passive Buzzer Piezo Speaker - 10mm Diammeter | https://www.digikey.com/product-detail/en/pui-audio-inc/AT-1224-TWT-5V-2-R/668-1470-ND/5011404 | R$0.00 | R$0.00
1 | Bluetooth Serial Communication Module | 034-001 | HC1 | HC-05 - RS232 | HC-05 - RS232 | HC-05 Embedded Bluetooth Serial Communication Module | https://www.gme.cz/data/attachments/dsh.772-148.1.pdf | R$0.00 | R$0.00
1 | Relay 12VDC - 5 Pin | 033-001 | K1 | metaltex AX1RC2 | 12VDC/10A - 5 Pin | Relay 12VDC/10A - 5 Pin for PCB | http://www.metaltex.com.br/downloads/AX.pdf | R$0.00 | R$0.00
1 | Display LCD 16 x 2 - Blue | 009-003 | DY1 | HD44780 - 16 x 2 LCD Display | HD44780 - 16 x 2 | Character LCD 2x16 Blue Display Module HD44780 White on Blue | https://www.sparkfun.com/datasheets/LCD/HD44780.pdf | R$0.00 | R$0.00
1 | Single Row Straight Male - 6 Pin - 180º | 024-003 | CN2 | A2-6PA-2.54DSA(71) | Single Row Straight Male - 6 Pin - 180º | Headers & Wire Housings 6P M PIN HEADER SR STRAIGHT TYPE GOLD | https://br.mouser.com/ProductDetail/Hirose-Connector/A2-6PA-254DSA71 | R$0.00 | R$0.00
1 | Duple Row Straight Male - 3 Pin - 180º | 024-004 | J1 | 5-146257-3 | Duple Row Straight Male - 3 Pin - 180º | Headers & Wire Housings 6P HEADER GOLD 30u double row | https://br.mouser.com/ProductDetail/TE-Connectivity/5-146257-3 | R$0.00 | R$0.00
1 | Single Row Straight Male - 16 Pin - 180º | 024-005 | DY1 | 1-826629-6 | Single Row Straight Male - 16 Pin - 180º | Headers & Wire Housings 16P SINGLE ROW | https://br.mouser.com/ProductDetail/TE-Connectivity-AMP/1-826629-6 | R$0.00 | R$0.00
1 | Single Row Straight Male - 23 Pin - 90º | 024-006 | CN3 | 22-28-8230 | Single Row Straight Male - 23 Pin - 90º | Headers & Wire Housings 2.54MM HDR RA 23P 244/120 SN | https://br.mouser.com/ProductDetail/Molex/22-28-8230 | R$0.00 | R$0.00
1 | Single Row Straight Female - 23 Pin - 180º | 024-007 | CN4 | BCS-123-L-S-HE | Single Row Straight Female - 23 Pin - 180º | Headers & Wire Housings .100" (2.54 mm) Tiger Claw Pass-through Socket Strip | https://br.mouser.com/ProductDetail/Samtec/BCS-123-L-S-HE | R$0.00 | R$0.00
2 | MOSFET - TO-220-3 | 012-003 | Q1, Q2 | Vishay - IRLZ44PBF | IRLZ44PBF | MOSFET N-Chan 60V/50A | https://br.mouser.com/ProductDetail/Vishay-Siliconix/IRLZ44PBF | R$0.00 | R$0.00
6 | Tactile Switch - SMD 6 x 6 x 5.0mm - 4 Pin | 019-001 | S1 - S6 | PTS645SH50SMTR92 LFS | PTS645SH50SMTR92 LFS | Tactile Switch - SMD - 6.00mm x 6.00mm X 5.0mm - 4 Pin | https://br.mouser.com/ProductDetail/CK/PTS645SH50SMTR92LFS | R$0.00 | R$0.00
1 | Trimpot 10K (103) - 3 Pin | 003-035 | PT3 | FPOT-10K | 10K (103) - 3 Pin | Single Turn Potentiometer 10K (103) for PCB - 3 Pin | https://static.rapidonline.com/pdf/68-0300e.pdf | R$0.00 | R$0.00
2 | Capacitor 0805 | 002-016 | C10, C11 | AVX Corporation - 08053A220KAT2A | 22pF | Ceramic Capacitor X7R 22pF NPO 10% 25V | https://br.mouser.com/ProductDetail/AVX/08053A220KAT2A | R$0.00 | R$0.00
6 | Capacitor 0805 | 002-007 | C1, C5 - C9 | AVX Corporation - 08051C104KAT2A | 100nF | Multilayer Ceramic Capacitors MLCC - SMD/SMT 100volts .1uF 10% | https://br.mouser.com/ProductDetail/AVX/08051C104KAT2A?qs=sGAEpiMZZMs0AnBnWHyRQFTaD8luxIJIioIkCKlsG8c%3d | R$0.00 | R$0.00
1 | Aluminum Electrolytic Capacitors 4,7uF/16V - SMD - 4x5.8mm | 002-019 | C4 | Panasonic - EEE-1CA4R7NR | 4,7uF/16V | Aluminum Electrolytic Capacitors - SMD 4,7uF/16V | https://br.mouser.com/ProductDetail/Panasonic/EEE-1CA4R7NR | R$0.00 | R$0.00
2 | Aluminum Electrolytic Capacitors 10uF/16V - SMD - 4x5.8mm | 002-035 | C2, C3 | Panasonic - EEE-FK1C100R | 10uF/16V | Aluminum Electrolytic Capacitors - SMD 10uF/16V | https://br.mouser.com/ProductDetail/Panasonic/EEE-FK1C100R | R$0.00 | R$0.00
2 | Connector Terminal Block - Green | 010-014 | GND - SLF1/SLF2 - LEVEL_S4 | Metaltex - BR7FN08 | BR7FN08 | Terminal blocks - Green pitch 3.81mm - 8 vias - Female - 90º | http://www.metaltex.com.br/downloads/BR.pdf | R$0.00 | R$0.00
1 | Connector Terminal Block - Green | 010-018 | NTC1 - VALVE4 | Metaltex - BR7FN06 | BR7FN06 | Terminal blocks - Green pitch 3.81mm - 6 vias - Female - 90º | http://www.metaltex.com.br/downloads/BR.pdf | R$0.00 | R$0.00
2 | Connector Terminal Block - Green | 010-013 | GND - SLF1/SLF2 - LEVEL_S4 | Metaltex - BR7MN08 | BR7MN08 | Terminal blocks - Green pitch 3.81mm - 8 vias - Male - 90º | http://www.metaltex.com.br/downloads/BR.pdf | R$0.00 | R$0.00
1 | Connector Terminal Block - Green | 010-019 | NTC1 - VALVE4 | Metaltex - BR7MN06 | BR7MN06 | Terminal blocks - Green pitch 3.81mm - 6 vias - Male - 90º | http://www.metaltex.com.br/downloads/BR.pdf | R$0.00 | R$0.00
4 | Optocouplers FOD817B DIP4 | 005-007 | OK1 - OK4 | Fairchild Semiconductor - FOD817B | FOD817B | Optoacoplador FOD817B 300W | https://br.mouser.com/ProductDetail/ON-Semiconductor-Fairchild/FOD817B?qs=AMp2PTjoga9wySUyhGmTyg%3D%3D | R$0.00 | R$0.00
1 | Connector Latch - IDCSC-34 | 010-026 | CN1 | Omron Electronics - XG4C-2031 | IDCSC-34 | Headers & Wire Housings Pitch: 2.54 mm BoxType Plug 34P Straight - 1 Polarize | https://br.mouser.com/ProductDetail/Omron-Electronics/XG4C-2031 | R$0.00 | R$0.00
1 | Jumper Male | 014-002 | JP1 | Sullins Connector Solutions - PRPC002SAAN-RC | PRPC002SAAN-RC | Jumpers connector (male for PCB) | https://www.digikey.com/product-detail/en/sullins-connector-solutions/PRPC002SAAN-RC/S1011EC-02-ND/2775252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 | R$0.00 | R$0.00
1 | Jumper Female | 014-001 | JP1 | Sullins Connector Solutions - NPC02SXON-RC | NPC02SXON-RC | Jumpers connector (female) | https://www.digikey.com/product-detail/en/sullins-connector-solutions/NPC02SXON-RC/S9341-ND/2618266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 | R$0.00 | R$0.00
1 | LED 3mm | 006-004 | D10 | Kingbright - WP710A10LYD | LED_YM_PTH | Yellow color LED 588nm YW WTR CLR | https://br.mouser.com/ProductDetail/Kingbright/WP710A10LYD | R$0.00 | R$0.00
1 | LED 3mm | 006-005 | D11 | Kingbright - WP710A10LGD | LED_GN_PTH | Green color LED 568nm GN WTR CLR | https://br.mouser.com/ProductDetail/Kingbright/WP710A10LGD | R$0.00 | R$0.00
2 | LED 3mm | 006-006 | D12, D13 | Kingbright - WP710A10LSRD | LED_RD_PTH | Red color LED 640nm RD WTR CLR | https://br.mouser.com/ProductDetail/Kingbright/WP710A10LSRD | R$0.00 | R$0.00
3 | LED 1206 | 006-007 | D7 - D9 | Kingbright - APT3216LSECK/J3-PRV | LED_RD_1206 | SMD Red color LED 630NM RD SURCK | https://br.mouser.com/ProductDetail/Kingbright/APT3216LSECK-J3-PRV | R$0.00 | R$0.00
1 | Voltage Regulator TO220 | 028-001 | U1 | Fairchild Semiconductor - MC78T05 | MC78T05 | 3-Terminal 3A Positive Voltage Regulator - 5V | https://br.mouser.com/ProductDetail/ON-Semiconductor-Fairchild/MC78T05CT | R$0.00 | R$0.00
1 | Microcontroler TQFP-64P | 005-012 | U2 | ATmega 2561-16AI Microchip Technology | ATmega 2561-16AI | 8-bit microcontroller ATmega 2561-16AI | https://br.mouser.com/ProductDetail/Microchip-Technology-Atmel/ATMEGA2561-16AI | R$0.00 | R$0.00
6 | Resistor 0805 | 003-003 | R16, R17, R18, R19, R22, R24 | Yageo - RC0805JR-071KL | 1K/5% | General Porpuse Chip Resistor 1K/5% | https://br.mouser.com/ProductDetail/Yageo/RC0805JR-071KL | R$0.00 | R$0.00
1 | Resistor 0805 | 003-024 | R27, R28, R26, R23 | Yageo - RC0805JR-071K5L | 1K5/5% | General Porpuse Chip Resistor 1K5/5% | https://br.mouser.com/ProductDetail/Yageo/RC0805JR-071K5L?qs=sGAEpiMZZMu61qfTUdNhG5eFuApKbqVd14K2fhosO80%3d | R$0.00 | R$0.00
1 | Resistor 0805 | 003-025 | R28 | Yageo - RC0805JR-072KL | 2K/5% | General Porpuse Chip Resistor 2K/5% | https://br.mouser.com/ProductDetail/Yageo/RC0805JR-072KL | R$0.00 | R$0.00
1 | Resistor 0805 | 003-014 | R26 | Yageo - RC0805JR-072K2L | 2K2/5% | General Porpuse Chip Resistor 2K2/5% | https://br.mouser.com/ProductDetail/Yageo/RC0805JR-072K2L | R$0.00 | R$0.00
1 | Resistor 0805 | 003-026 | R23 | Yageo - RC0805JR-073K3L | 3K3/5% | General Porpuse Chip Resistor 3K3/5% | https://br.mouser.com/ProductDetail/Yageo/RC0805JR-073K3L | R$0.00 | R$0.00
2 | Resistor 0805 | 003-004 | R4, R6 | Yageo - RC0805JR-074K7L | 4K7/5% | General Porpuse Chip Resistor 4K7/5% | https://br.mouser.com/ProductDetail/Yageo/RC0805JR-074K7L | R$0.00 | R$0.00
3 | Resistor 0805 | 003-005 | R8, R14, R15 | Yageo - RC0805JR-0710KL | 10K/5% | General Porpuse Chip Resistor 10K/5% | https://br.mouser.com/ProductDetail/Yageo/RC0805JR-0710KL | R$0.00 | R$0.00
1 | Resistor 0805 | 003-006 | R25 | Yageo - RC0805JR-0712KL | 12K/5% | General Porpuse Chip Resistor 12K/5% | https://br.mouser.com/ProductDetail/Yageo/RC0805JR-0712KL?qs=sGAEpiMZZMu61qfTUdNhG6gKAQVNBKOoeUFUSB8c1lw%3d | R$0.00 | R$0.00
2 | Resistor 0805 | 003-046 | R5, R7 | Yageo - RC0805JR-07100KL | 100K/5% | General Porpuse Chip Resistor 100K/5% | https://br.mouser.com/ProductDetail/Yageo/RC0805JR-07100KL | R$0.00 | R$0.00
3 | Resistor 0805 | 003-016 | R9 - R11 | Yageo - RC0805JR-07220RL | 220R/5% | General Porpuse Chip Resistor 220R/5% | https://br.mouser.com/ProductDetail/Yageo/RC0805JR-07220RL?qs=sGAEpiMZZMu61qfTUdNhG5eFuApKbqVdJm8qxbTqIJw%3d | R$0.00 | R$0.00
4 | Resistor 0805 | 003-017 | R1, R12, R13, R20 | Yageo - CR1206-JW-331ELF | 330R/5% | General Porpuse Chip Resistor 330R/5% | https://br.mouser.com/ProductDetail/Bourns/CR1206-JW-331ELF | R$0.00 | R$0.00
1 | Resistor 0805 | 003-018 | R3 | Yageo - RC0805JR-07510RL | 510R/5% | General Porpuse Chip Resistor 510R/5% | https://br.mouser.com/ProductDetail/Yageo/RC0805JR-07510RL?qs=sGAEpiMZZMu61qfTUdNhG5eFuApKbqVd2JG8XrUfGuU%3d | R$0.00 | R$0.00
1 | Resistor 0805 | 003-030 | R21 | Yageo - RC0805JR-07620RL | 620R/5% | General Porpuse Chip Resistor 620R/5% | https://br.mouser.com/ProductDetail/Yageo/RC0805JR-07620RL | R$0.00 | R$0.00
1 | Resistor 0805 | 003-047 | R2 | Yageo - RC0805JR-07220KL | 220K/5% | General Porpuse Chip Resistor 220K/5% | https://br.mouser.com/ProductDetail/Yageo/RC0805JR-07220KL?qs=sGAEpiMZZMu61qfTUdNhG6gKAQVNBKOoMPx3vljC42k%3d | R$0.00 | R$0.00
2 | Transistor SOT-23 | 012-001 | Q3, Q4 | MCC - BC846B-TP SMD/SOT-23 | BC846B-TP | Transistores bipolares de junção - BJT 65V, 100mA | https://br.mouser.com/ProductDetail/Micro-Commercial-Components-MCC/BC846B-TP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 | R$0.00 | R$0.00
1 | Zener Diode - SMD - SOD-323 | 004-009 | D1 | ON Semiconductor - MM3Z3V3T1G | MM3Z3V3T1G | Zener Diodes 3V3 200mW | https://br.mouser.com/ProductDetail/ON-Semiconductor/MM3Z3V3T1G | R$0.00 | R$0.00
2 | Diode LL4148 SOD-80 | 004-007 | D6, D14 | Vishay - LL4148 | LL4148 - SOD-80 | Small Signal Fast Switching Diodes | https://br.mouser.com/ProductDetail/ON-Semiconductor-Fairchild/1N4148?qs=sGAEpiMZZMudZehw8RjeZWbu6z6oTQTL | R$0.00 | R$0.00
4 | Diode S1G DO-214AC | 004-002 | D2 - D5 | Vishay - S1G-E3/61T | S1G | S1G Diode General Purpose - 400V - 1A | https://br.mouser.com/ProductDetail/Vishay-Semiconductors/S1G-E3-61T | R$0.00 | R$0.00
1 | XTAL SMD Crystal - HC-49/US | 013-006 | XT1 | ECS-160-20-5G3XDS-TR | 16.00MHz | Crystal 16.0000MHz 10ppm 20pF 40 Ohms -40°C + 125°C | https://br.mouser.com/ProductDetail/ECS/ECS-160-20-5G3XDS-TR | R$0.00 | R$0.00
1 | PCB Painel_V2.1 | 020-008 |  | Painel_V2.1 |  | PCB Painel_V2.1 |  |  | R$0.00
1 | PCB EZBrewControl V2.1 | 020-009 |  | EZBrewControl |  | PCB EZBrewControl V2.1 |  | TOTAL | R$0.00
 |  |  |  |  |  | V

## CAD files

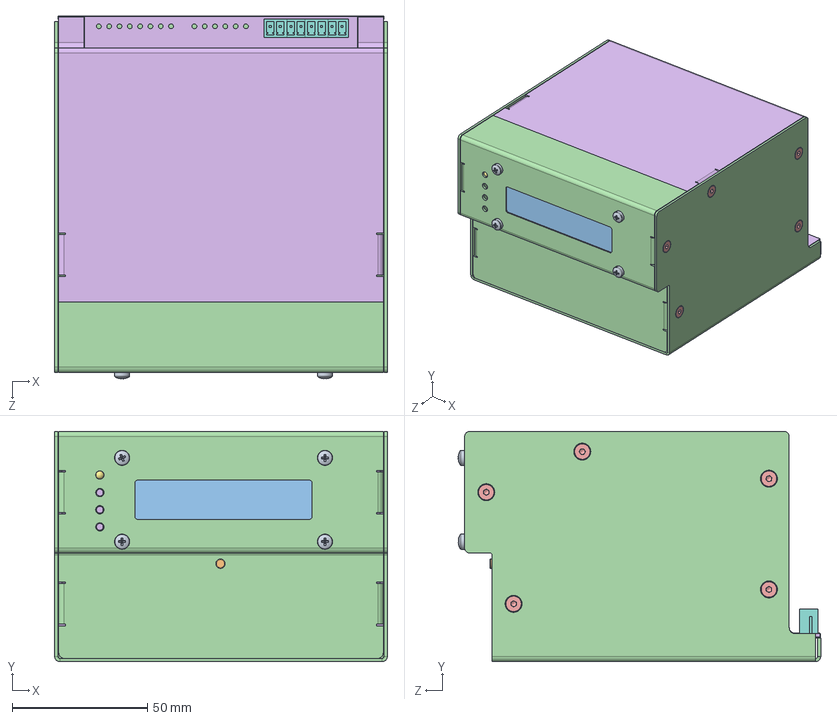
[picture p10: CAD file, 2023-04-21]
ENSABrewMechanicalProject/Version 2.0/Montagem - EZBrew-100A_V2.SLDASM
123.1 x 85.2 x 134.0 mm
EZBrewControl Painel_V3.0
DisplayLCD
EZBrew-100A - TampaSuperiorFrente_V2
Standoff M3x10mm x 4
EZBrewControlCPU_V3.0
KF2EDGVR 3_81 x 4
pan cross head_am x 4
DS1022-1x7RUF11 x 5
HEADER6PFEM x 4
EZBrew-100A - Gabinete_V2
socket countersunk head screw_din x 10
EZBrew-100A - TampaSuperiorTraseira_V2

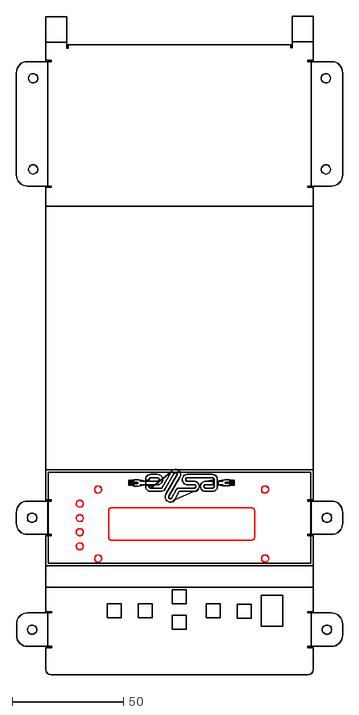
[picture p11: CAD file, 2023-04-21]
ENSABrewMechanicalProject/Version 2.0/Adesivo/EZBrew-100A - TampaSuperior_V2.DXF
146.5 x 295.7

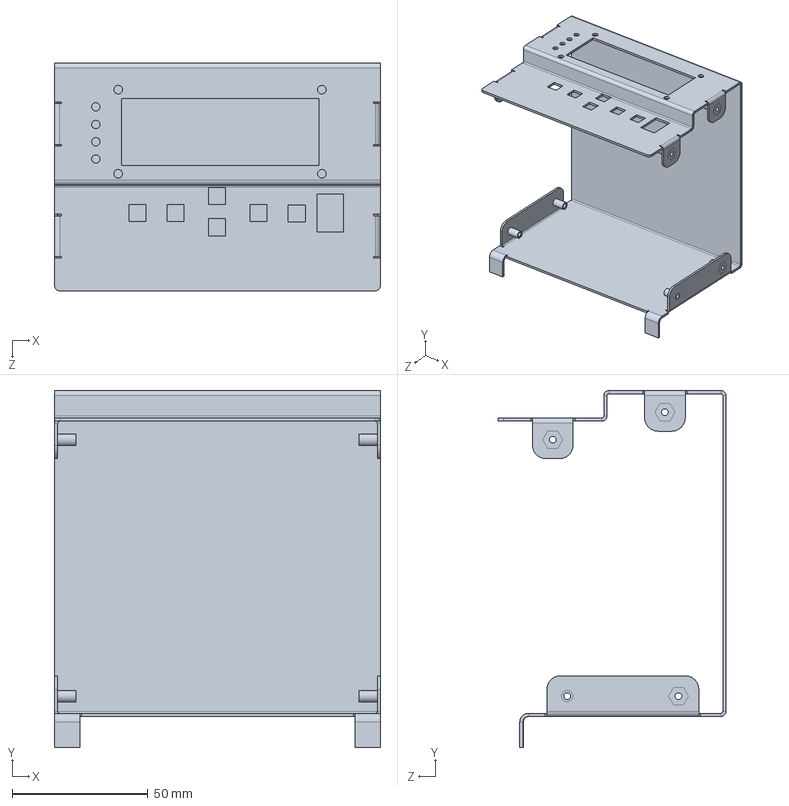
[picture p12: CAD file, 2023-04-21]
ENSABrewMechanicalProject/Version 2.0/EZBrew3D/EZBrew-100A - TampaSuperior V2.SLDPRT
120.0 x 131.4 x 84.0 mm

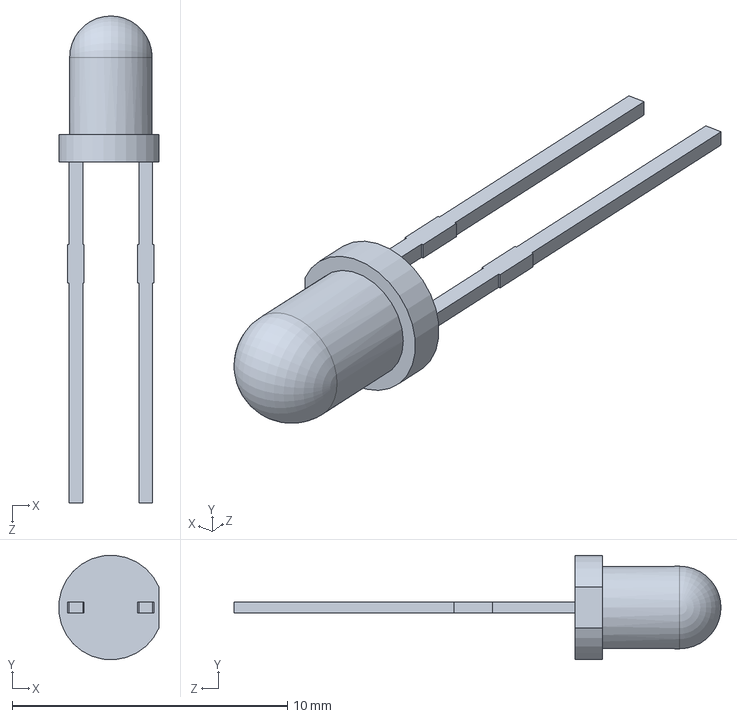
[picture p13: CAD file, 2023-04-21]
ENSABrewMechanicalProject/Version 2.0/LED_3mm.SLDPRT
3.64 x 3.79 x 17.7 mm

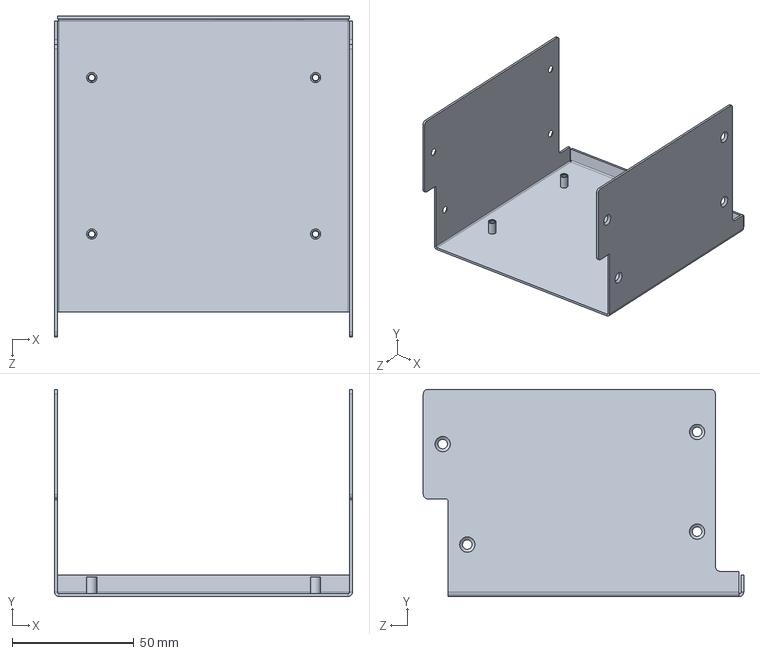
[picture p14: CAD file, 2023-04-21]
ENSABrewMechanicalProject/Version 2.0/EZBrew3D/EZBrew-100A - Gabinete_V2.SLDPRT
122.4 x 85.2 x 131.7 mm

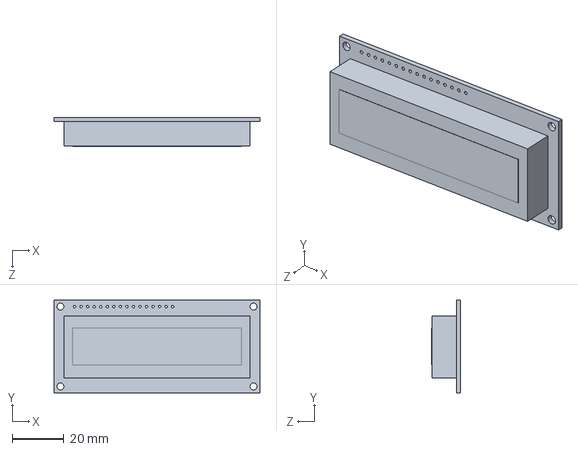
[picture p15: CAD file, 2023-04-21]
ENSABrewMechanicalProject/Version 2.0/DisplayLCD.SLDPRT
80.0 x 36.0 x 11.2 mm

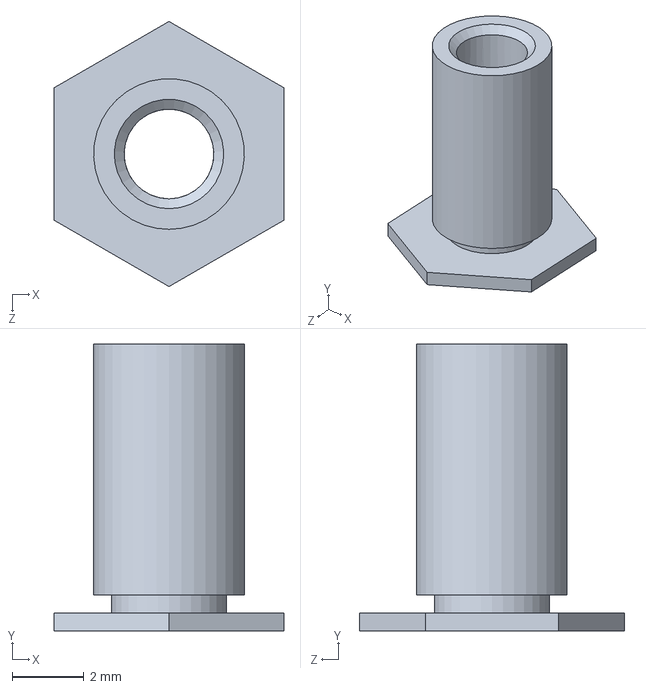
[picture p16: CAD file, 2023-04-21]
ENSABrewMechanicalProject/Version 2.0/Espacador-M3x8.SLDPRT
6.40 x 8.00 x 7.39 mm

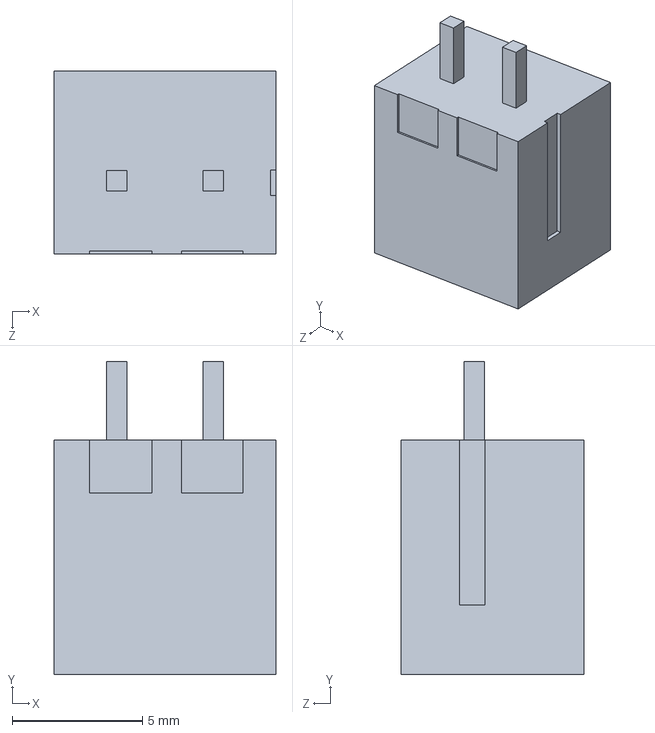
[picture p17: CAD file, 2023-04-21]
ENSABrewMechanicalProject/Version 2.0/KF2EDGVR 3_81.SLDPRT
8.50 x 12.0 x 7.00 mm

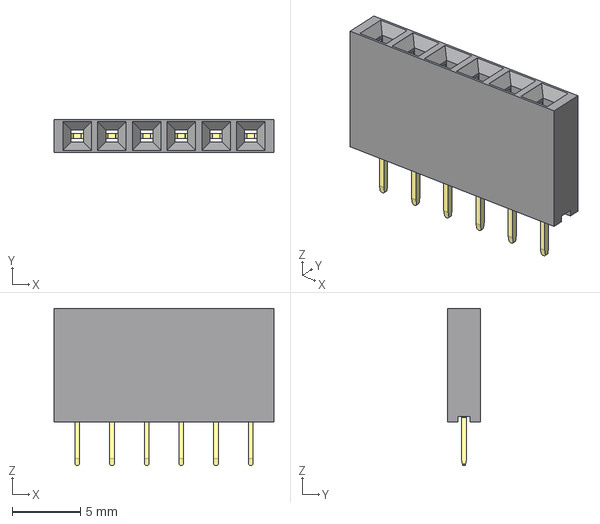
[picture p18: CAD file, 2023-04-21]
ENSABrewMechanicalProject/Version 2.0/HEADER6PFEM.stp
16.1 x 2.40 x 11.5 mm

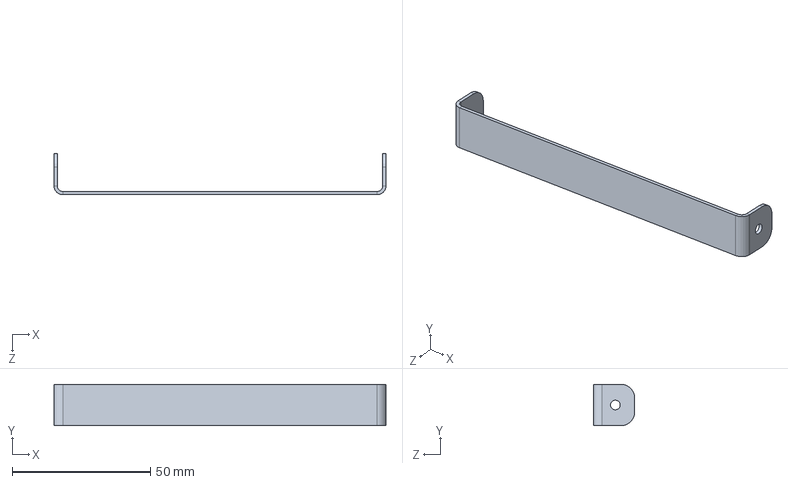
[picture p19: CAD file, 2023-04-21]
ENSABrewMechanicalProject/Version 2.0/EZBrew-100A - ApoioPCB_V2.SLDPRT
120.0 x 15.0 x 15.0 mm

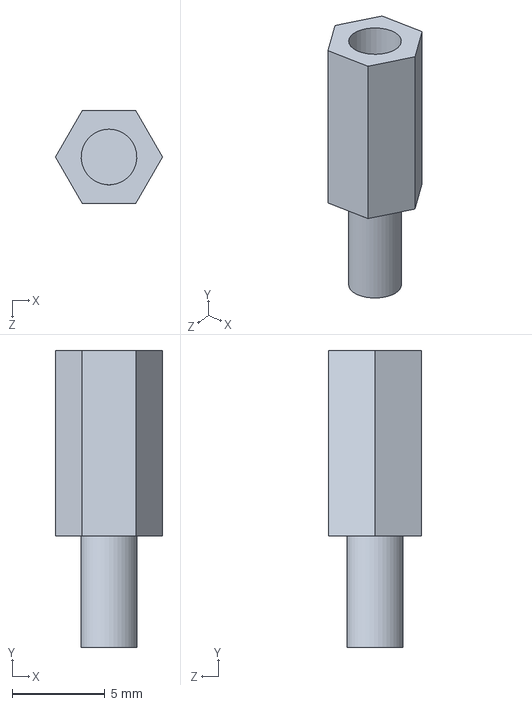
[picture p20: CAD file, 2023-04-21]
ENSABrewMechanicalProject/Version 2.0/Standoff M3x10mm.SLDPRT
5.77 x 16.0 x 5.00 mm

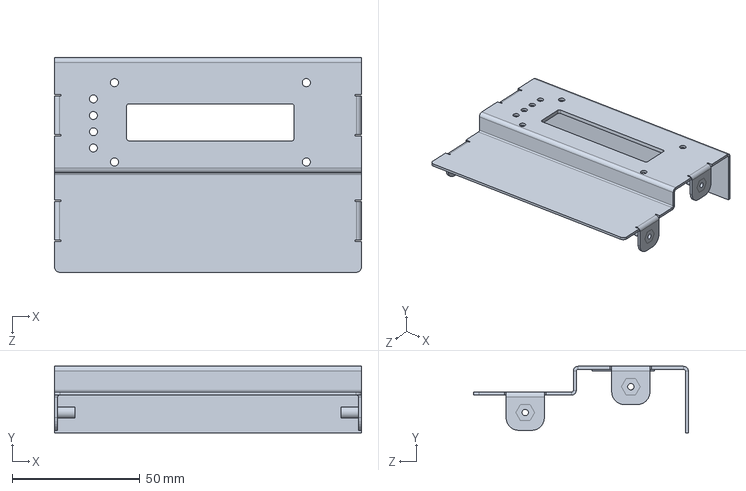
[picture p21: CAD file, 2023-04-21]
ENSABrewMechanicalProject/Version 2.0/EZBrew-100A - TampaSuperiorFrente_V2.SLDPRT
120.0 x 26.0 x 84.0 mm

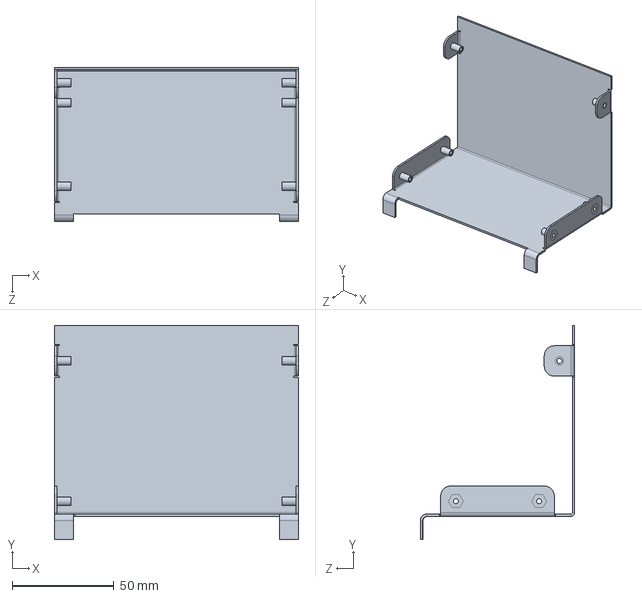
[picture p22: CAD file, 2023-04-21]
ENSABrewMechanicalProject/Version 2.0/EZBrew-100A - TampaSuperiorTraseira_V2.SLDPRT
120.0 x 105.4 x 76.0 mm

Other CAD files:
ENSABrewMechanicalProject/Version 2.0/Drawings/EZBrew-100A - CL - TampaSuperiorFrente_V2.DWG
ENSABrewMechanicalProject/Version 2.0/Drawings/EZBrew-100A - CL - Gabinete V2.DWG
ENSABrewMechanicalProject/Version 2.0/Padrão plano - EZBrew-100A - TampaSuperiorTraseira_V2.DWG
ENSABrewMechanicalProject/Version 2.0/Drawings/EZBrew-100A - CL - TampaSuperiorTraseira_V2.DWG
ENSABrewMechanicalProject/Version 2.0/EZBrew-100A - Gabinete_V2.SLDPRT
ENSABrewMechanicalProject/Version 1.0/Adesivo/AdesivoConectores.DXF
ENSABrewMechanicalProject/Version 1.0/Adesivo/EZBrew-100A - TampaSuperior.DXF
ENSABrewMechanicalProject/Version 1.0/Drawings/EZBrew-100A - ApoioPCB.SLDDRW
ENSABrewMechanicalProject/Version 1.0/Drawings/EZBrew-100A - CL - ApoioPCB.DWG
ENSABrewMechanicalProject/Version 1.0/Drawings/EZBrew-100A - CL - Gabinete.DWG
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

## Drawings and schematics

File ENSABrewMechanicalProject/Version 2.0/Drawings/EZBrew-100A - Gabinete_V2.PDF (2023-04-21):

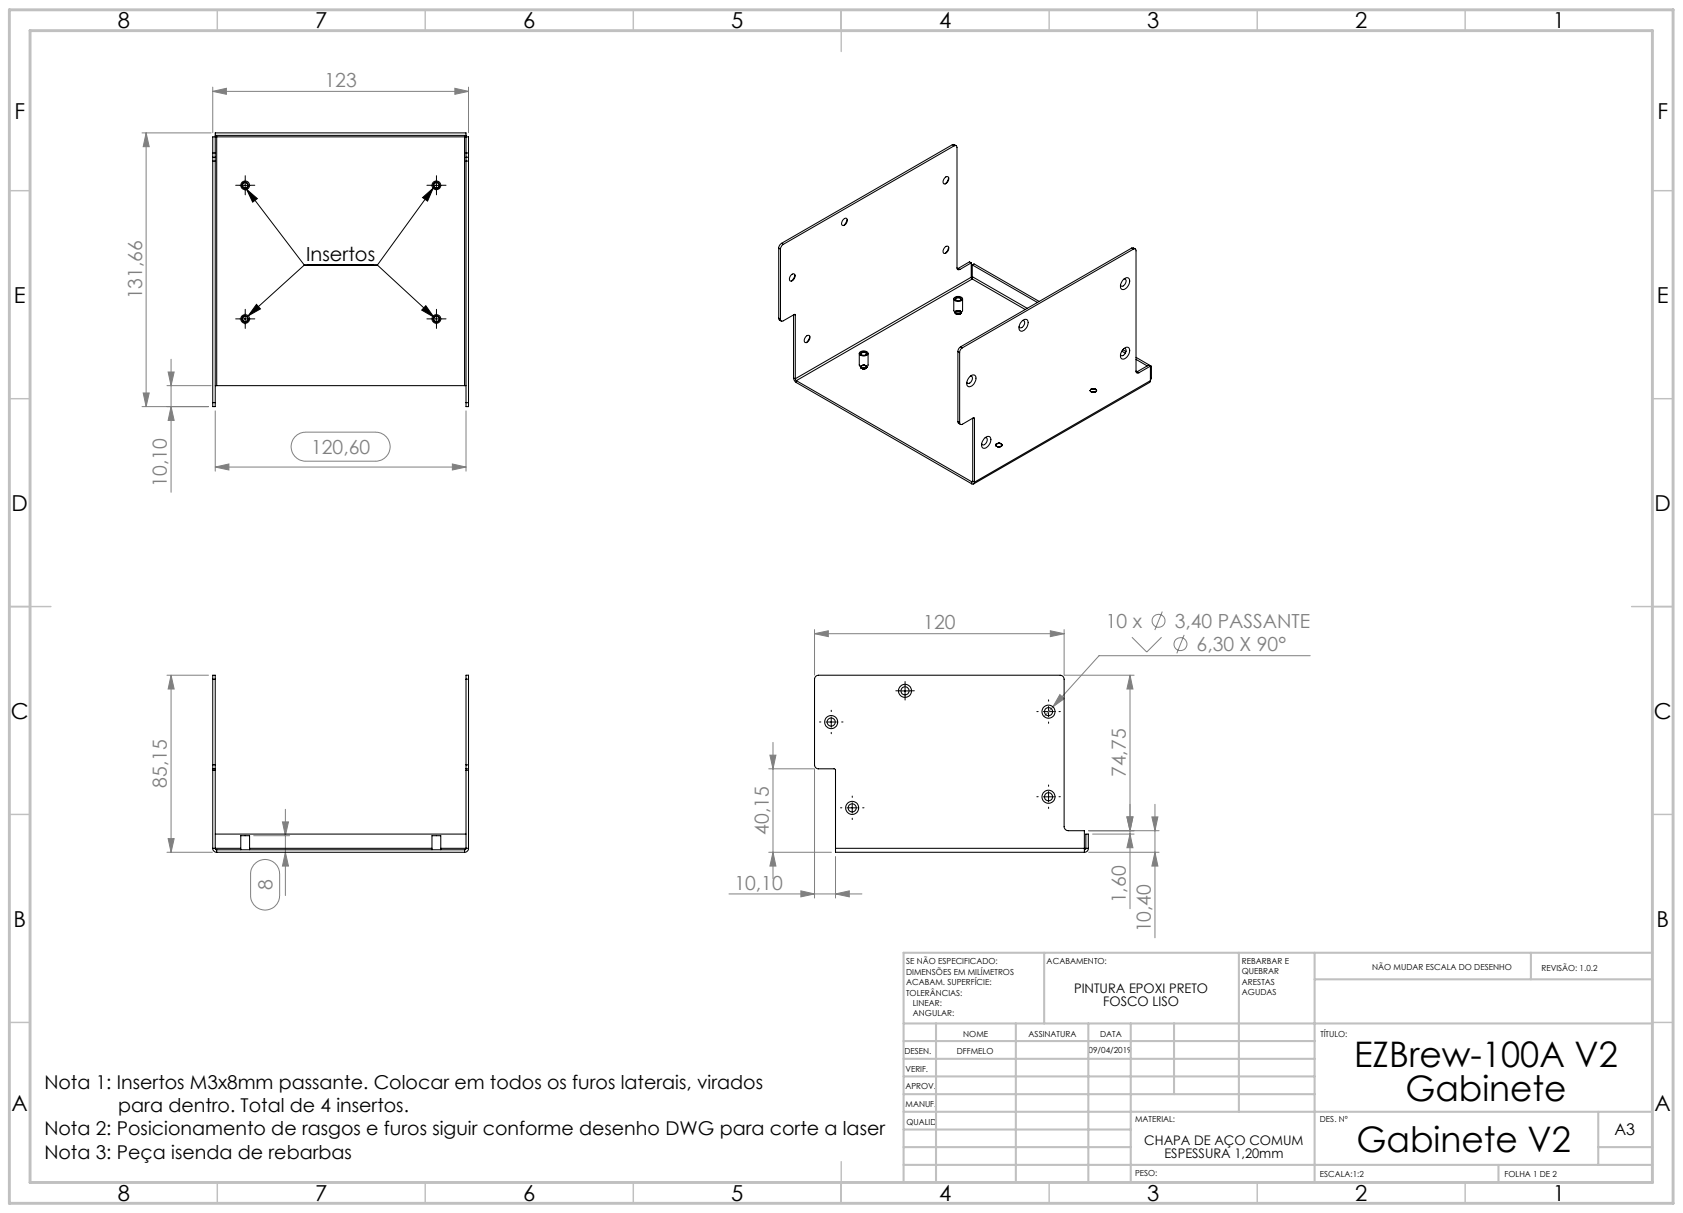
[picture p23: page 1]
3,40 PASSANTE; ACABAMENTO:; REBARBAR E; NÃO MUDAR ESCALA DO DESENHO; REVISÃO: 1.0.2; ESCALA:1:2; FOLHA 1 DE 2

SE NÃO ESPECIFICADO:
DIMENSÕES EM MILÍMETROS
ACABAM. SUPERFÍCIE:
TOLERÂNCIAS:
LINEAR:
ANGULAR:

PINTURA EPOXI PRETO
FOSCO LISO

NOME | ASSINATURA | DATA | | | | TÍTULO: EZBrew-100A V2 Gabinete

DESEN. | DFFMELO | | 09/04/2019
VERIF.
APROV.
MANUF.
QUALID | | | | MATERIAL: ESPESSURA 1,20mm | DES. Nº Gabinete V2 | A3 CHAPA DE AÇO COMUM

Nota 1: Insertos M3x8mm passante. Colocar em todos os furos laterais, virados
Nota 2: Posicionamento de rasgos e furos siguir conforme desenho DWG para corte a laser
Nota 3: Peça isenda de rebarbas

para dentro. Total de 4 insertos.

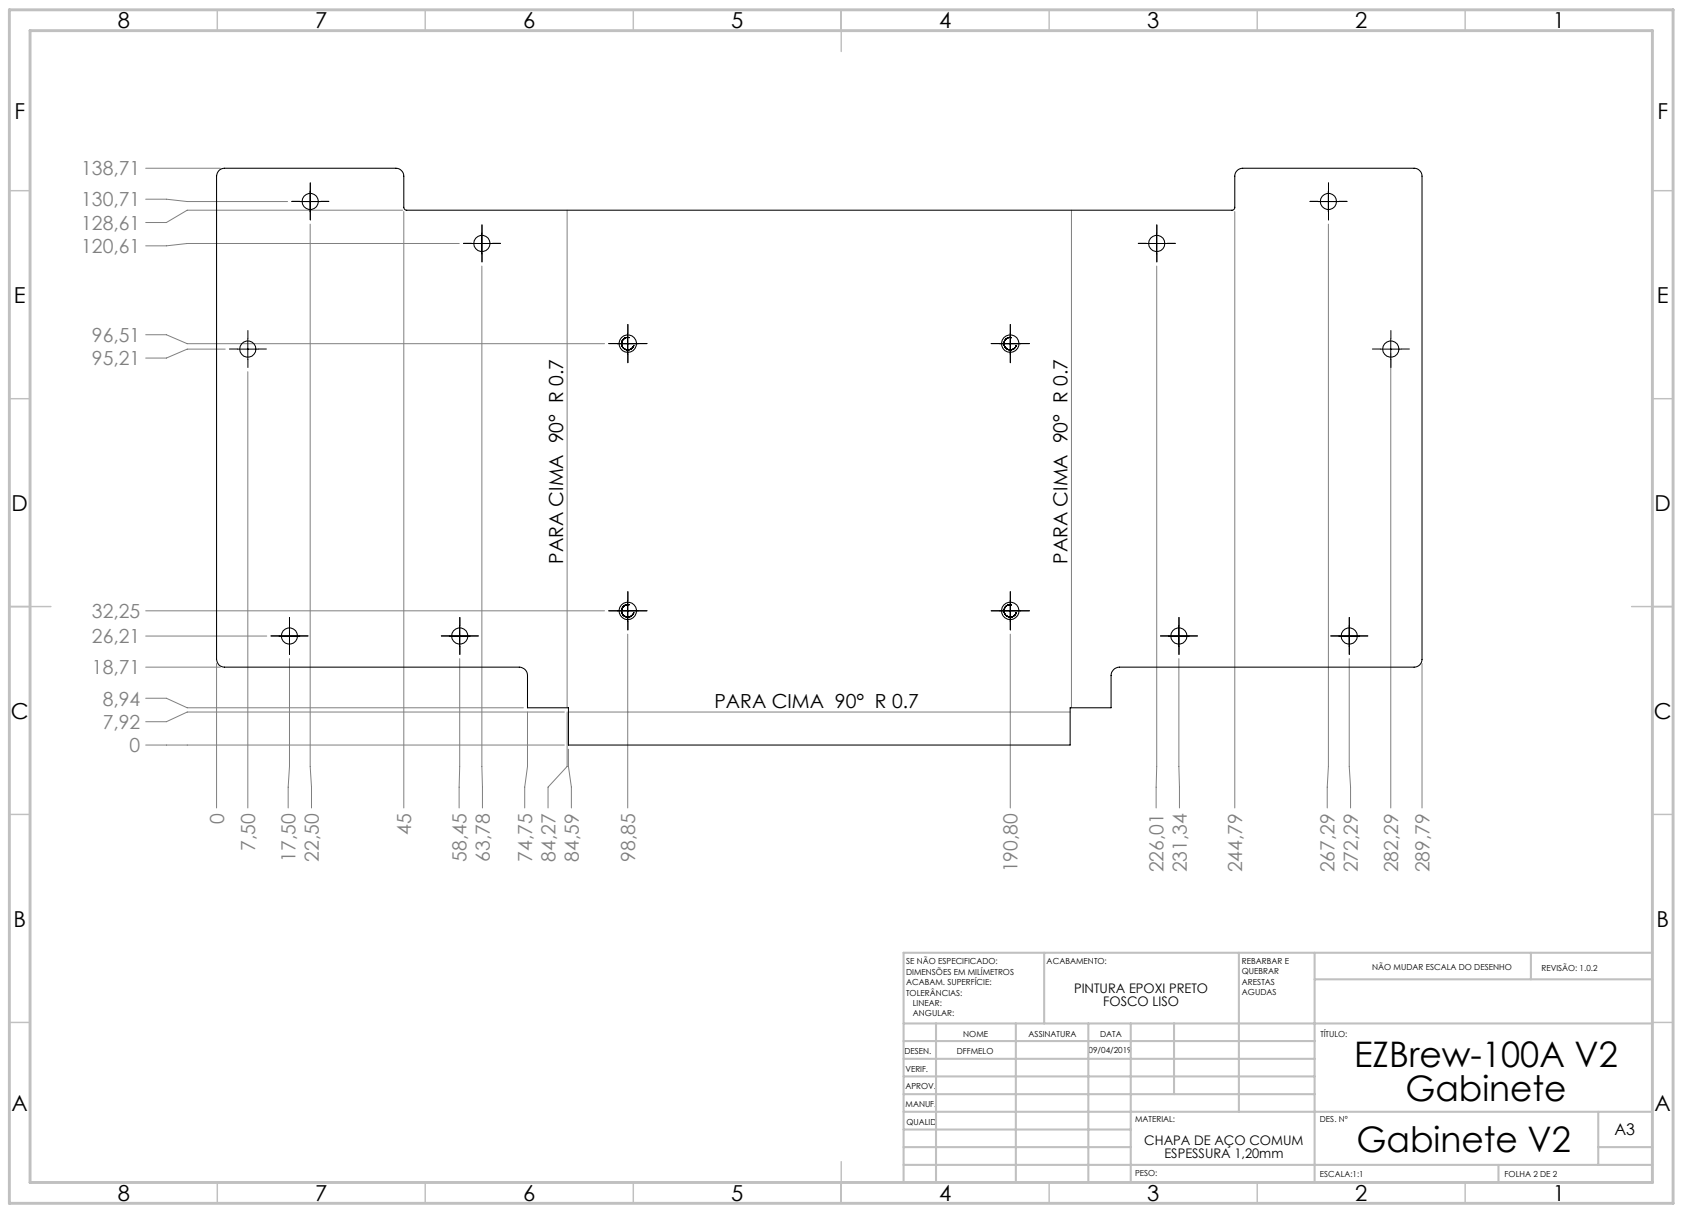
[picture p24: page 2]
PARA CIMA 90° R 0.7; ACABAMENTO:; REBARBAR E; NÃO MUDAR ESCALA DO DESENHO; REVISÃO: 1.0.2; ESCALA:1:1; FOLHA 2 DE 2

SE NÃO ESPECIFICADO:
DIMENSÕES EM MILÍMETROS
ACABAM. SUPERFÍCIE:
TOLERÂNCIAS:
LINEAR:
ANGULAR:

PINTURA EPOXI PRETO
FOSCO LISO

NOME | ASSINATURA | DATA | | | | TÍTULO: EZBrew-100A V2 Gabinete

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

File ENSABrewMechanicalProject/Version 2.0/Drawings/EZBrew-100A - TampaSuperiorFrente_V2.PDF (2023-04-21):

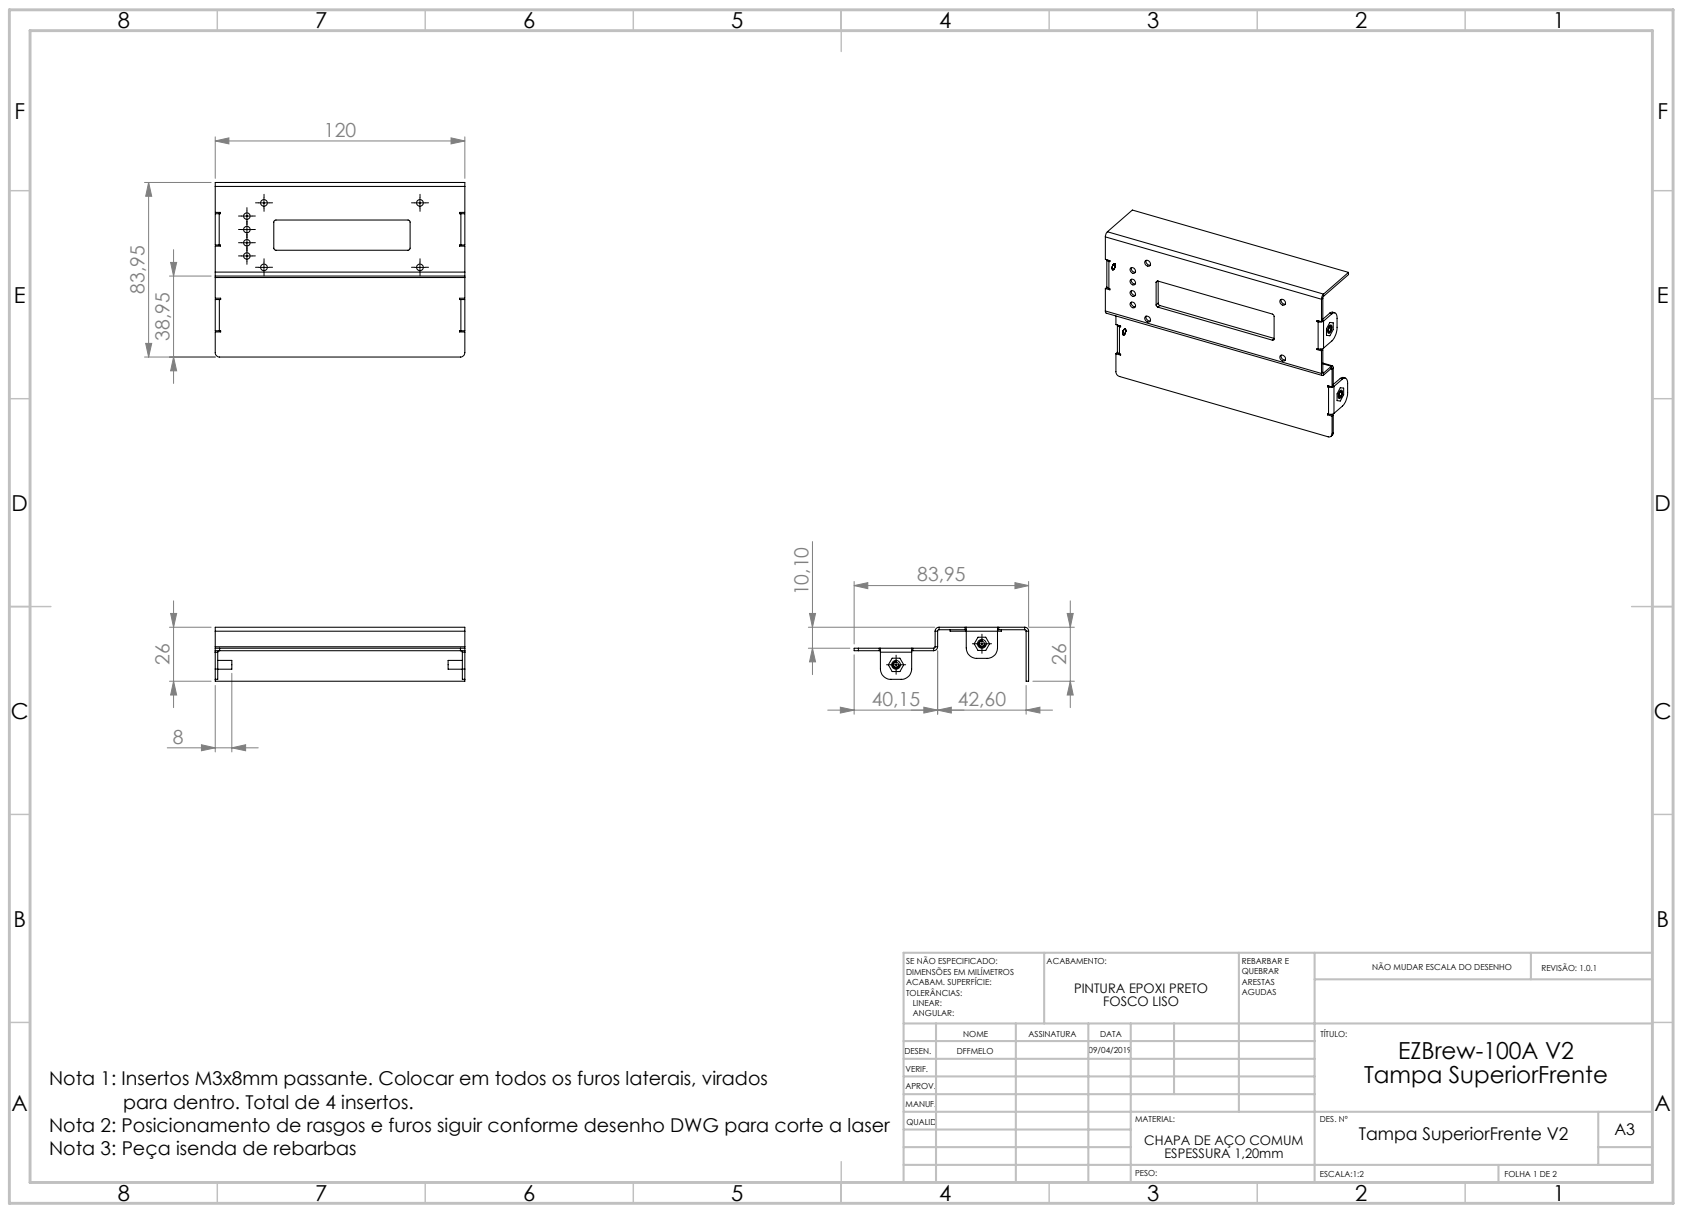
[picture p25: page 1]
ACABAMENTO:; REBARBAR E; NÃO MUDAR ESCALA DO DESENHO; REVISÃO: 1.0.1; ESCALA:1:2; FOLHA 1 DE 2

SE NÃO ESPECIFICADO:
DIMENSÕES EM MILÍMETROS
ACABAM. SUPERFÍCIE:
TOLERÂNCIAS:
LINEAR:
ANGULAR:

PINTURA EPOXI PRETO
FOSCO LISO

NOME | ASSINATURA | DATA | | | | TÍTULO: EZBrew-100A V2 Tampa SuperiorFrente

DESEN. | DFFMELO | | 09/04/2019
VERIF.
APROV.
MANUF.
QUALID | | | | MATERIAL: ESPESSURA 1,20mm | DES. Nº Tampa SuperiorFrente V2 | A3 CHAPA DE AÇO COMUM

Nota 1: Insertos M3x8mm passante. Colocar em todos os furos laterais, virados
Nota 2: Posicionamento de rasgos e furos siguir conforme desenho DWG para corte a laser
Nota 3: Peça isenda de rebarbas

para dentro. Total de 4 insertos.

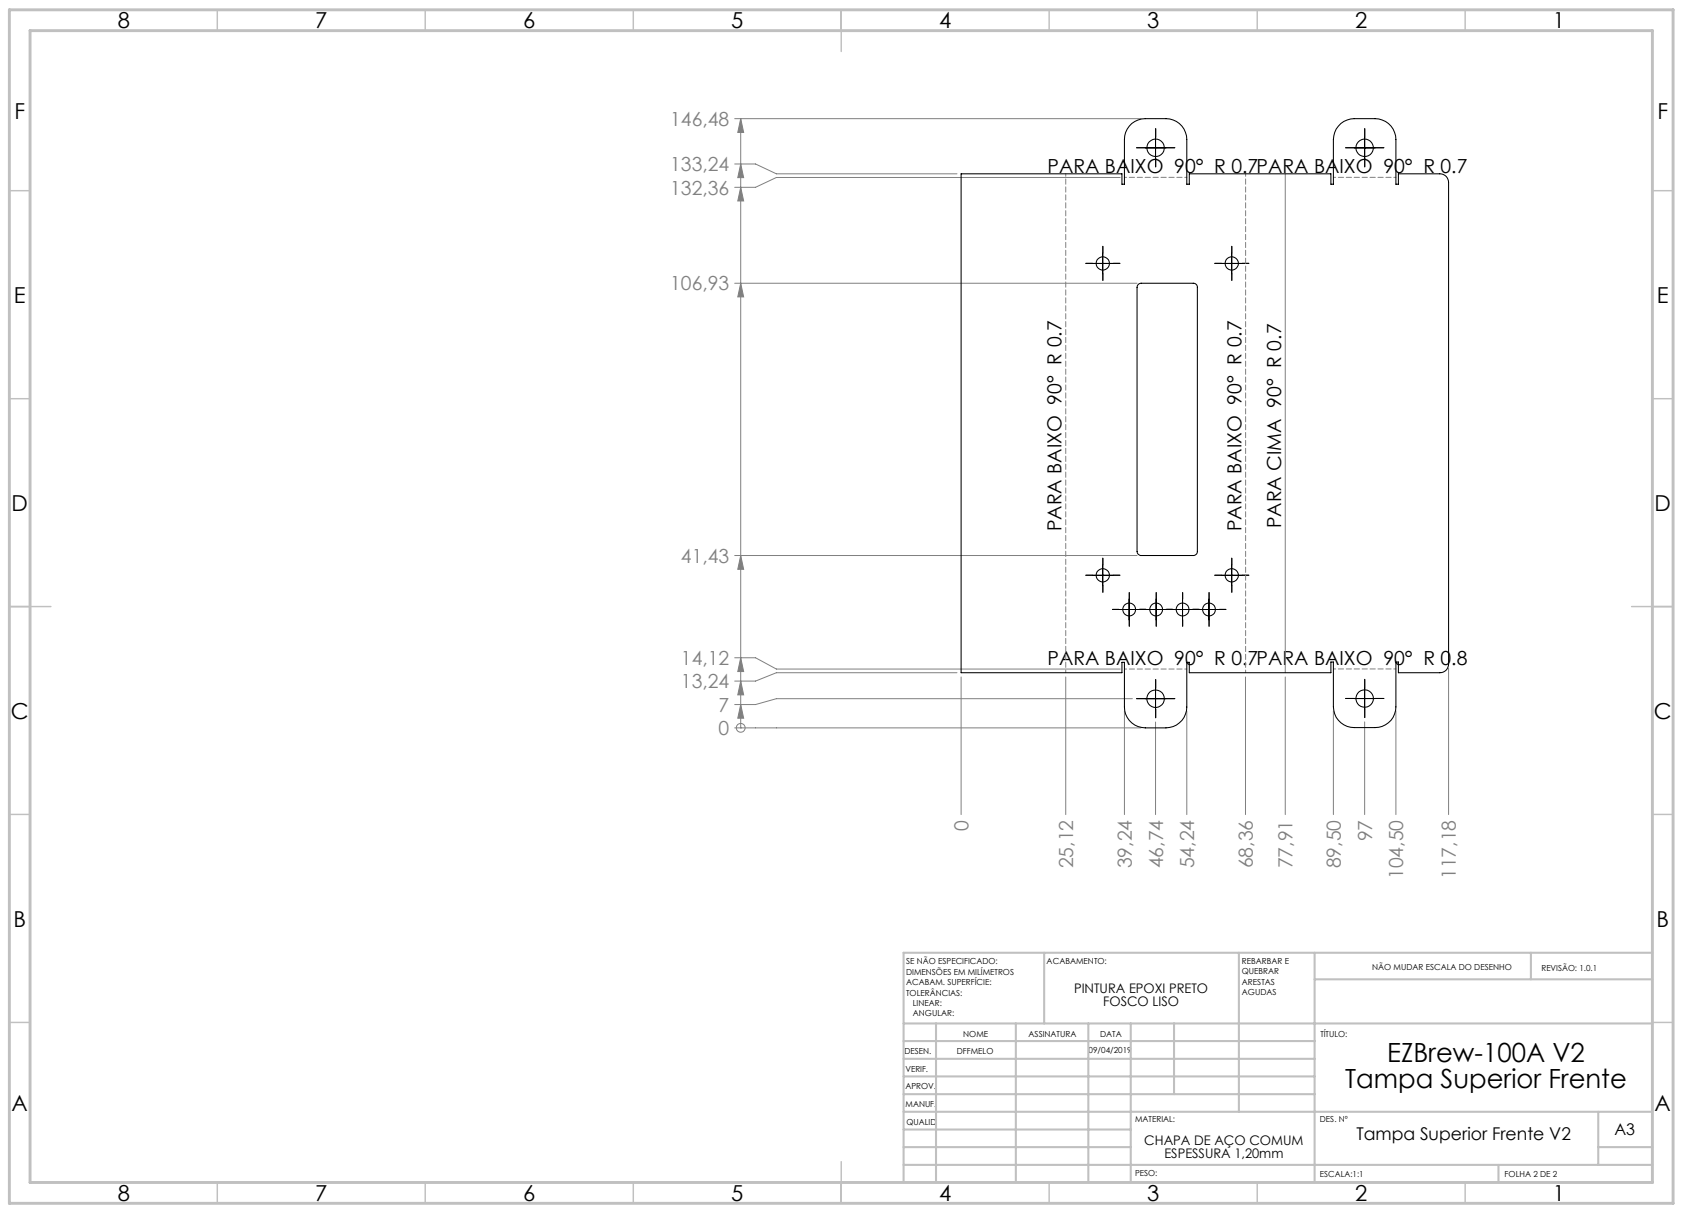
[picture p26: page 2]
PARA BAIXO 90° R 0.7 PARA BAIXO 90° R 0.8 PARA BAIXO 90° R 0.7; PARA BAIXO 90° R 0.7; PARA CIMA 90° R 0.7; ACABAMENTO:; REBARBAR E; NÃO MUDAR ESCALA DO DESENHO; REVISÃO: 1.0.1; ESCALA:1:1; FOLHA 2 DE 2

PARA BAIXO 90° R 0.7

SE NÃO ESPECIFICADO:
DIMENSÕES EM MILÍMETROS
ACABAM. SUPERFÍCIE:
TOLERÂNCIAS:
LINEAR:
ANGULAR:

PINTURA EPOXI PRETO
FOSCO LISO

NOME | ASSINATURA | DATA | | | | TÍTULO: EZBrew-100A V2 Tampa Superior Frente

DESEN. | DFFMELO | | 09/04/2019
VERIF.
APROV.
MANUF.
QUALID | | | | MATERIAL: ESPESSURA 1,20mm | DES. Nº Tampa Superior Frente V2 | A3 CHAPA DE AÇO COMUM

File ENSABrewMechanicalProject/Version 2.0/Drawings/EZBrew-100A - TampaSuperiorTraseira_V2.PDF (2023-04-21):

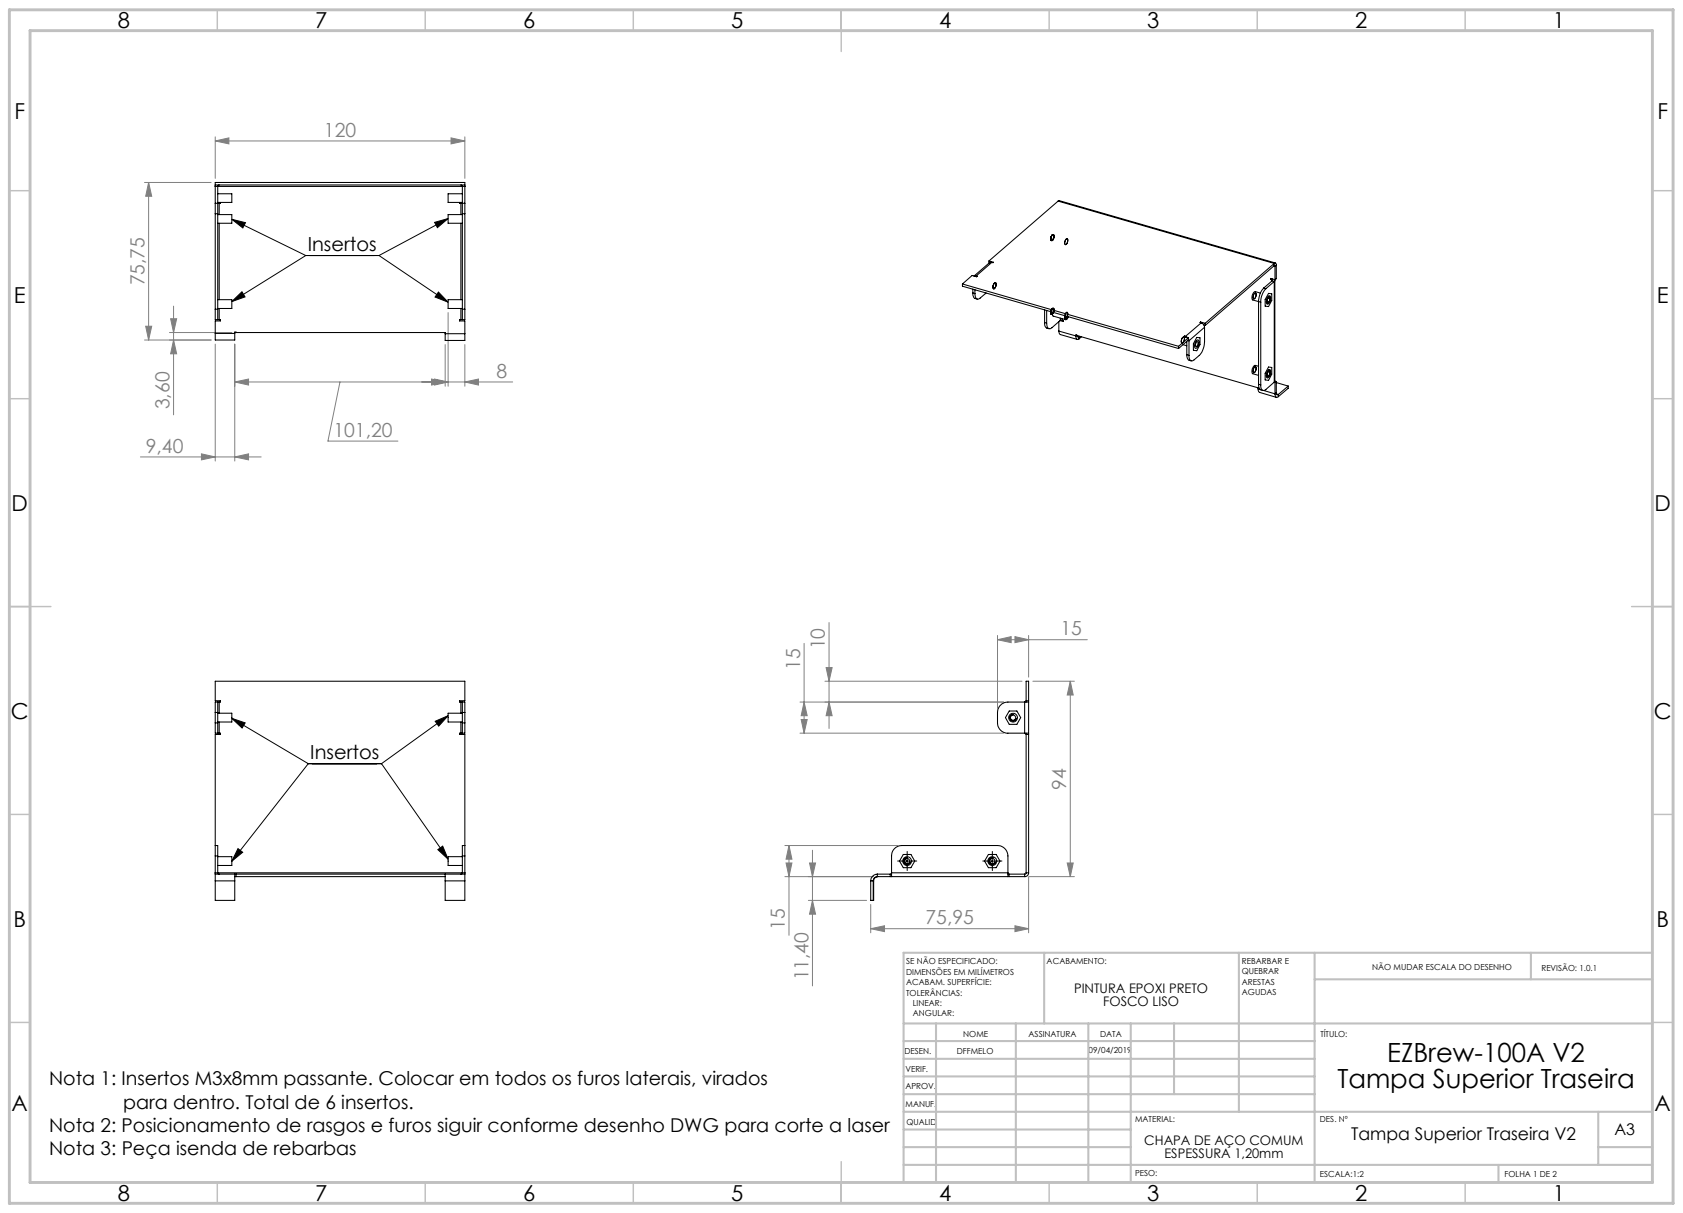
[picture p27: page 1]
ACABAMENTO:; REBARBAR E; NÃO MUDAR ESCALA DO DESENHO; REVISÃO: 1.0.1; ESCALA:1:2; FOLHA 1 DE 2

SE NÃO ESPECIFICADO:
DIMENSÕES EM MILÍMETROS
ACABAM. SUPERFÍCIE:
TOLERÂNCIAS:
LINEAR:
ANGULAR:

PINTURA EPOXI PRETO
FOSCO LISO

NOME | ASSINATURA | DATA | | | | TÍTULO: EZBrew-100A V2 Tampa Superior Traseira

DESEN. | DFFMELO | | 09/04/2019
VERIF.
APROV.
MANUF.
QUALID | | | | MATERIAL: ESPESSURA 1,20mm | DES. Nº Tampa Superior Traseira V2 | A3 CHAPA DE AÇO COMUM

Nota 1: Insertos M3x8mm passante. Colocar em todos os furos laterais, virados
Nota 2: Posicionamento de rasgos e furos siguir conforme desenho DWG para corte a laser
Nota 3: Peça isenda de rebarbas

para dentro. Total de 6 insertos.

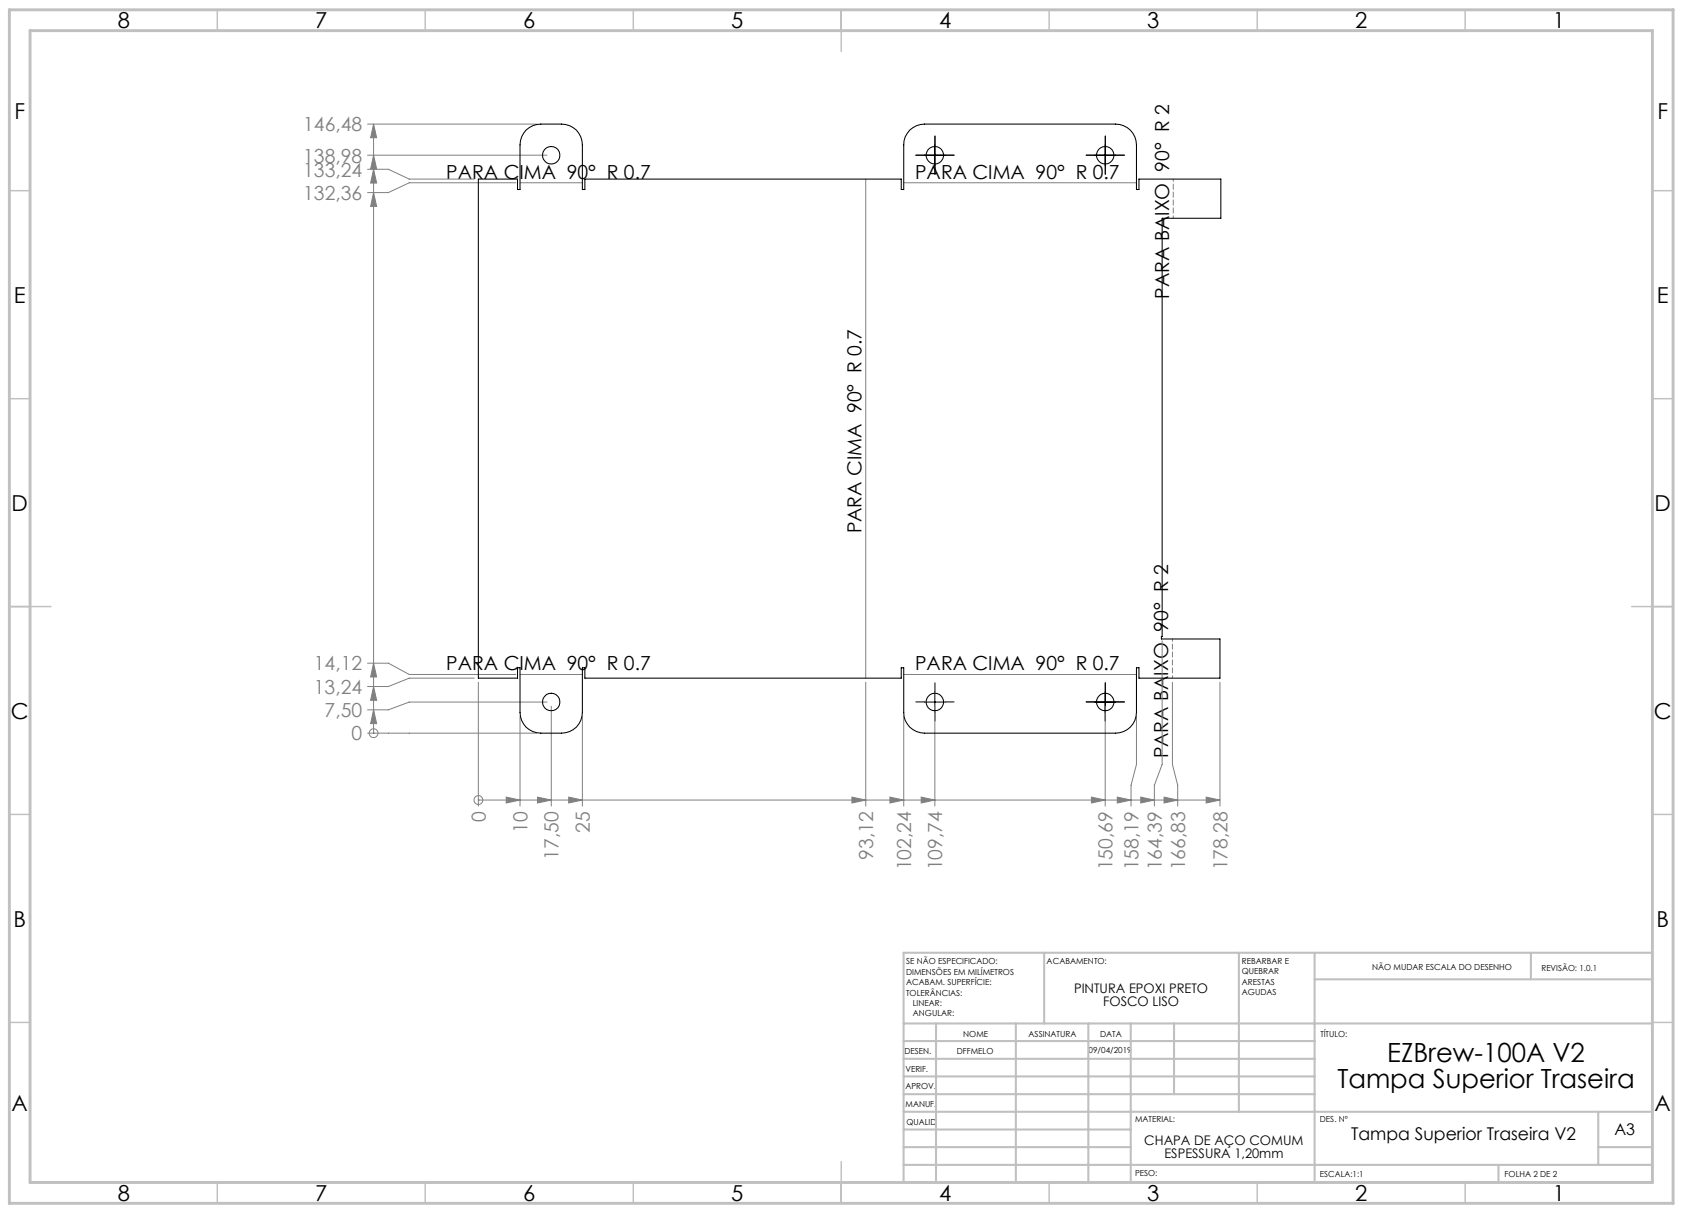
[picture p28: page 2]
PARA CIMA 90° R 0.7; ACABAMENTO:; REBARBAR E; NÃO MUDAR ESCALA DO DESENHO; REVISÃO: 1.0.1; ESCALA:1:1; FOLHA 2 DE 2

PARA BAIXO 90° R 2

SE NÃO ESPECIFICADO:
DIMENSÕES EM MILÍMETROS
ACABAM. SUPERFÍCIE:
TOLERÂNCIAS:
LINEAR:
ANGULAR:

PINTURA EPOXI PRETO
FOSCO LISO

NOME | ASSINATURA | DATA | | | | TÍTULO: EZBrew-100A V2 Tampa Superior Traseira

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

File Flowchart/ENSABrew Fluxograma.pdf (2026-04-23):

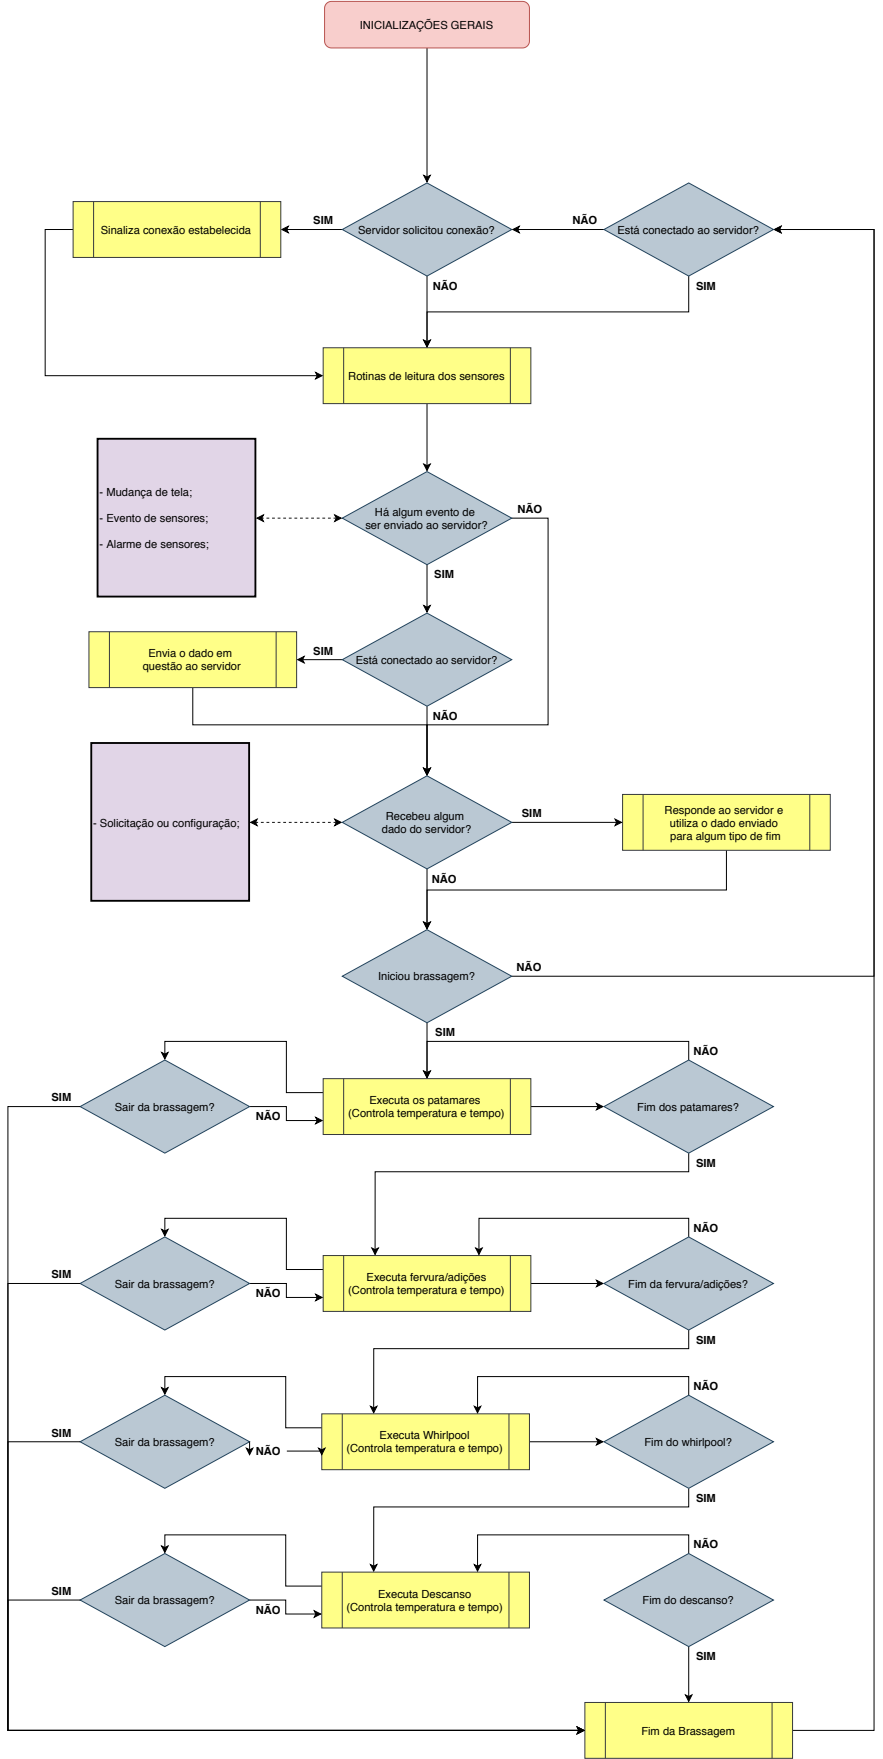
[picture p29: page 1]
INICIALIZAÇÕES GERAIS; NÃO; SIM; Recebeu algum; Sinaliza conexão estabelecida; Servidor solicitou conexão?; Iniciou brassagem?; (Controla temperatura e tempo); Fim dos patamares?; Fim da fervura/adições?; Executa Whirlpool; Fim do whirlpool?; Executa Descanso; Fim do descanso?

Está conectado ao servidor?

Rotinas de leitura dos sensores

- Mudança de tela;

Há algum evento de
ser enviado ao servidor?

- Evento de sensores;

- Alarme de sensores;

Envia o dado em
questão ao servidor

dado do servidor?

Responde ao servidor e
utiliza o dado enviado
para algum tipo de fim

- Solicitação ou configuração;

Sair da brassagem?

Executa os patamares

Executa fervura/adições

Fim da Brassagem

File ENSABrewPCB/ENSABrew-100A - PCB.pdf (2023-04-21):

101.0 mm

# D10 GND

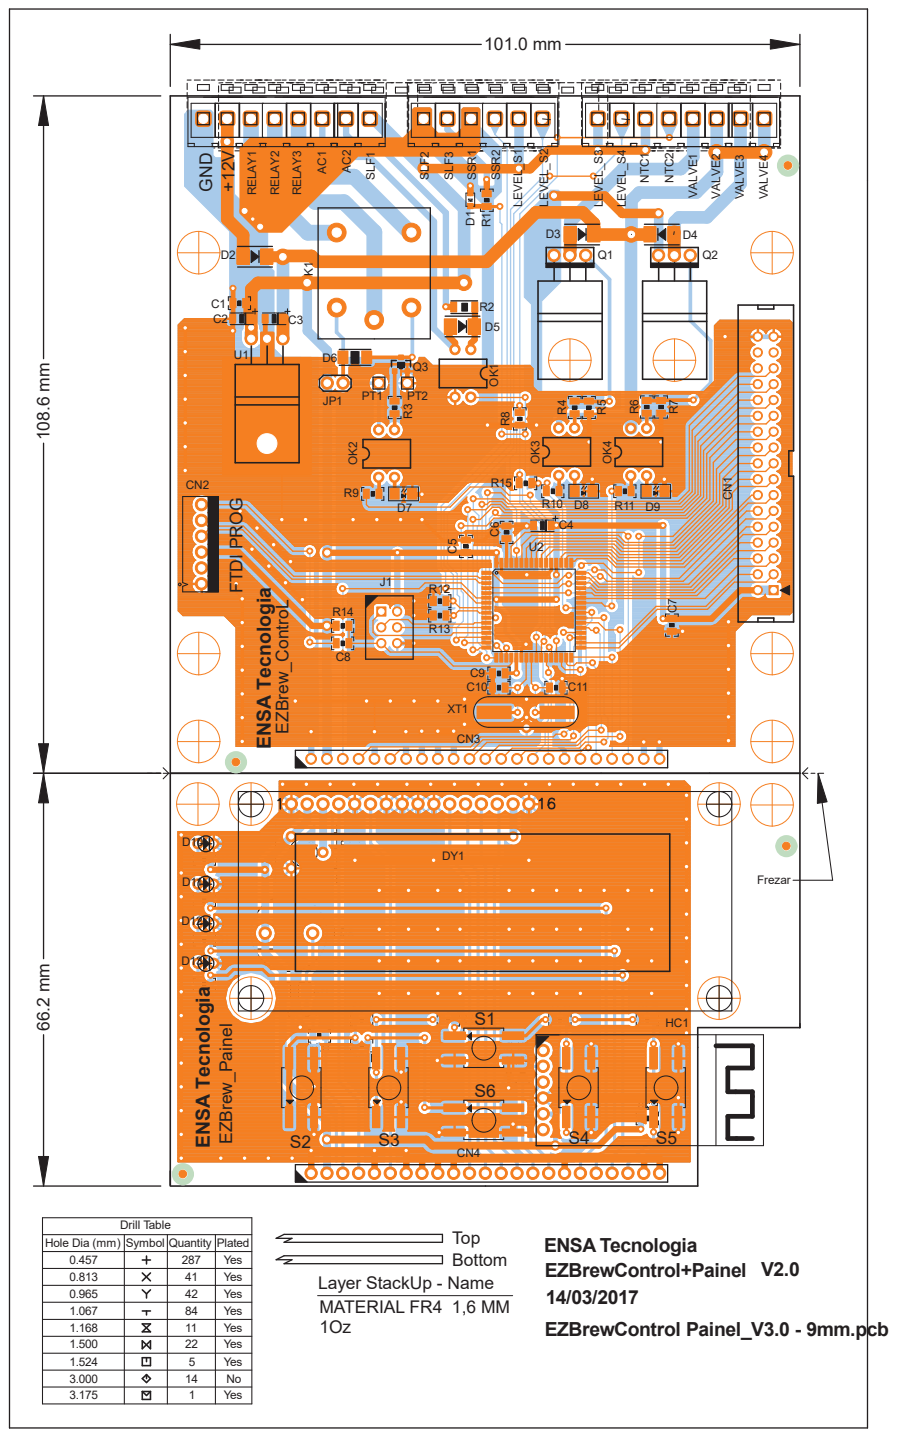
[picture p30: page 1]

Hole Dia (mm) | Symbol | Quantity | Plated
0.457 | | 287 | Yes
0.813 | | 41 | Yes
0.965 | | 42 | Yes
1.067 | | 84 | Yes
1.168 | | 11 | Yes
1.500 | | 22 | Yes
1.524 | | 5 | Yes
3.000 | | 14 | No
3.175 | | 1 | Yes

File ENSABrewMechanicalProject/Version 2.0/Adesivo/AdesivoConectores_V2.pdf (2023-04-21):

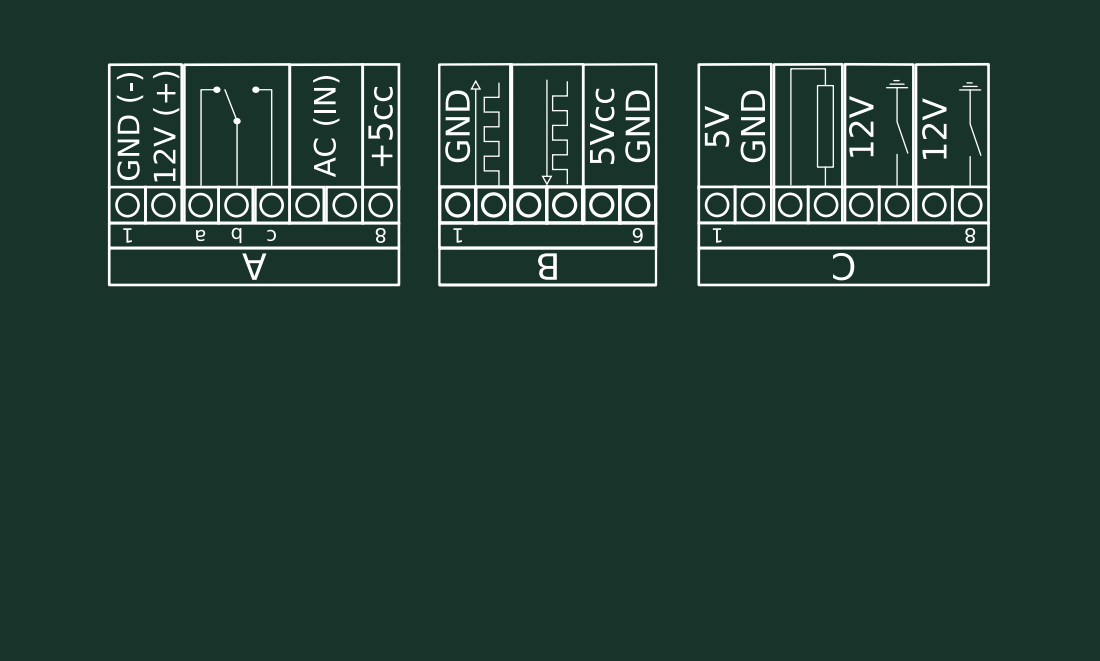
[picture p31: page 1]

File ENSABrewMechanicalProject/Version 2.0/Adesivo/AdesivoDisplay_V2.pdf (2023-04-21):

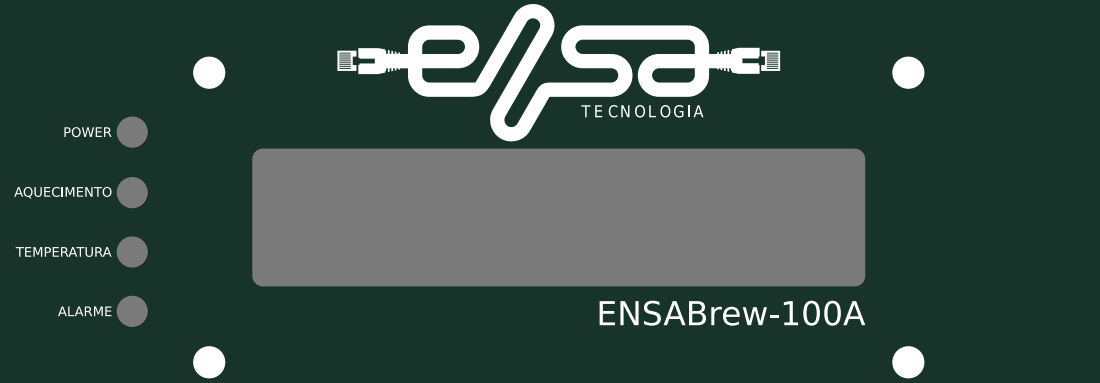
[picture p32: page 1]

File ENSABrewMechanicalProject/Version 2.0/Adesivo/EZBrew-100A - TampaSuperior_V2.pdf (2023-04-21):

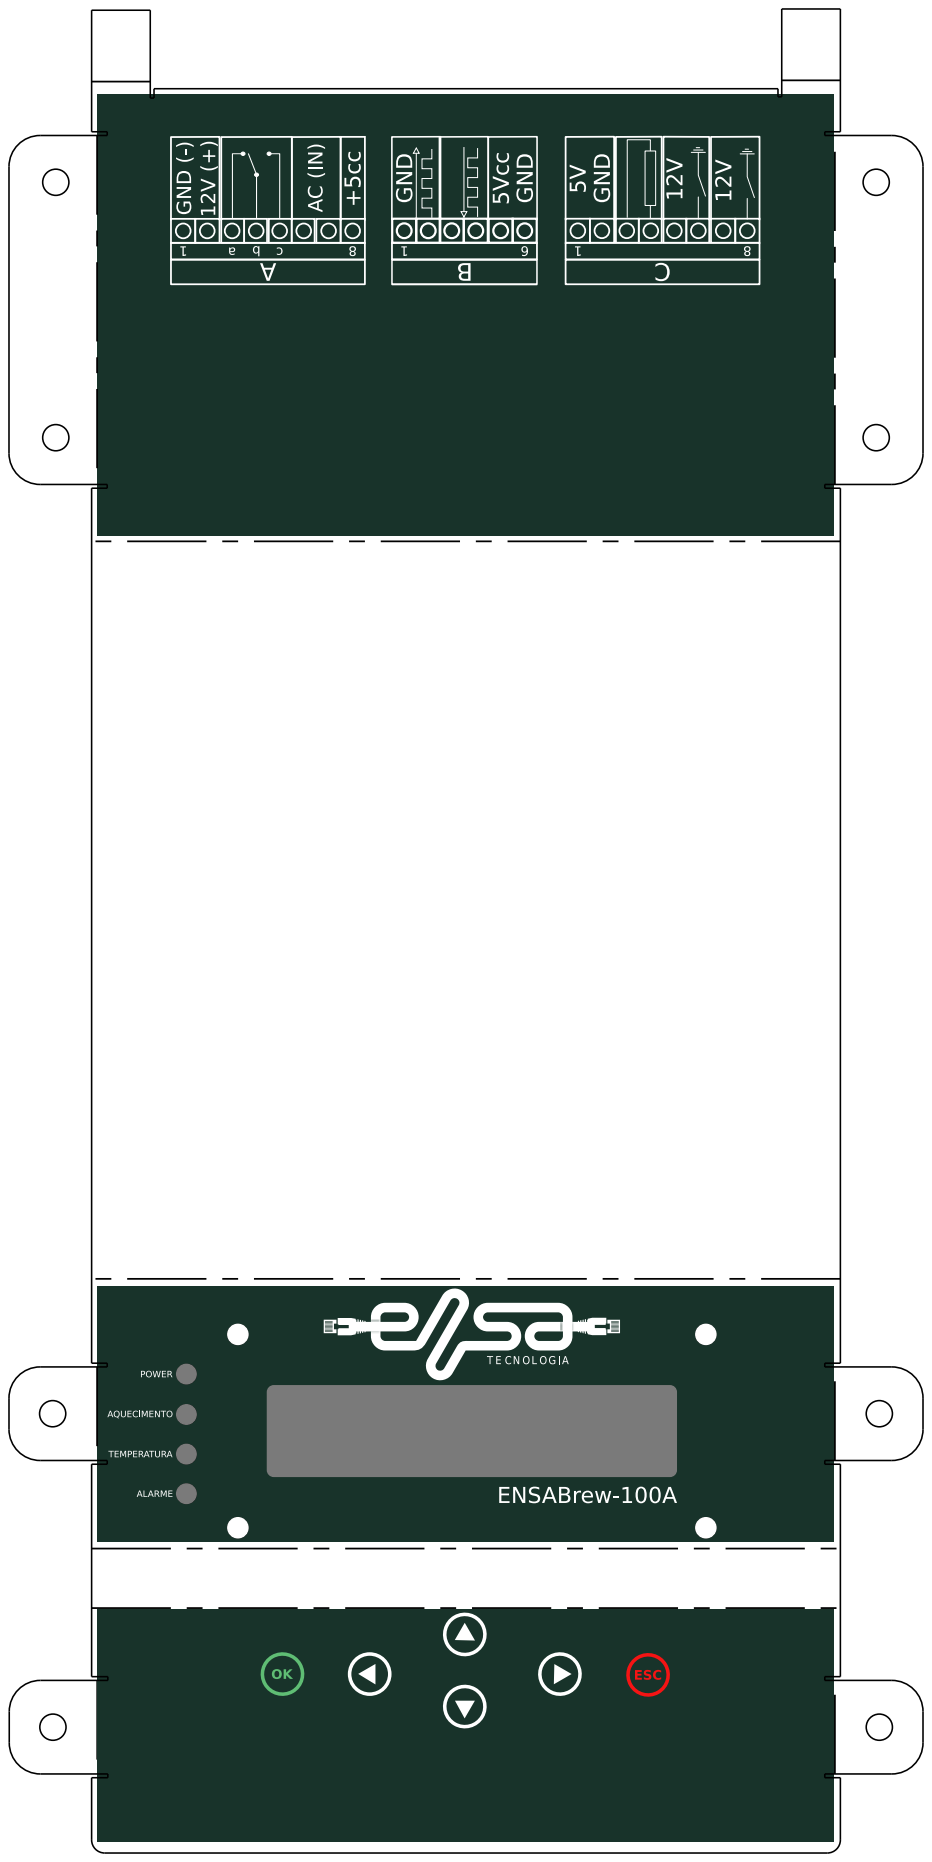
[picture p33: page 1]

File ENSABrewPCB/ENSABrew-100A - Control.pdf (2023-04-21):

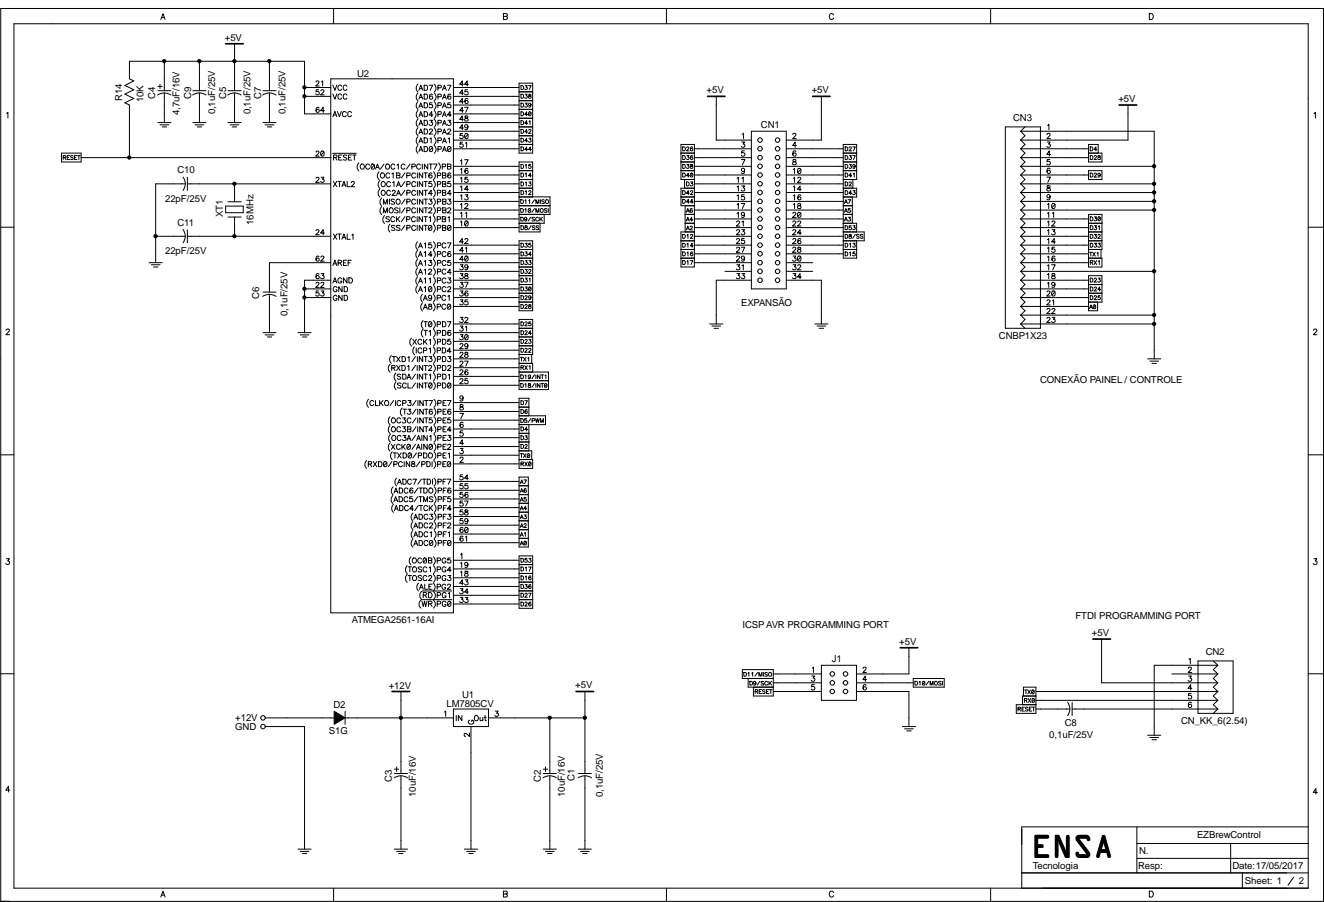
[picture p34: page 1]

ICSP AVR PROGRAMMING PORT

ENSA Tecnologia | EZBrewControl

N.
Resp: | Date: 17/05/2017

Sheet: 1 2

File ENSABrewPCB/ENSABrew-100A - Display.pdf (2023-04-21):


ENSA Tecnologia | EZBrewControl

N.
Resp: | Date: 14/03/2017

Sheet: 1 3

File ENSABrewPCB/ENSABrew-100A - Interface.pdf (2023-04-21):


ENSA Tecnologia | EZBrewControl

N.
Resp: | Date: 17/05/2017

Sheet: 2 2

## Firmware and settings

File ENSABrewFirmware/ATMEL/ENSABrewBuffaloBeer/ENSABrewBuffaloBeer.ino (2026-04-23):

//*******************************************************************************************
// Arquivo C/C++ do Projeto Controlador de Patamares -- ENSABrewControl
//-------------------------------------------------------------------------------------------
//
// Arquivo: ENSABrewMain.ino
//
// Autor  : Cláudio B. Pimenta, A.S
// Autor  : Jânio Anselmo, Eng. Me.
// Autor  : Thiago Anselmo, Tecgº
// Autor  : Gabriel da Silva Caetano
//
// CPU    : ATMega2561 - MegaCore
// Clock  : 16MHz
//
//*******************************************************************************************

#include "Libraries/Wire/Wire.cpp"
#include "Libraries/EEPROM/EEPROM.h"
#include "Libraries/TimerOne/TimerOne.cpp"
// #include "Libraries/Arduino_PID/PID_v1.cpp"
#include "Libraries/TimerFour/TimerFour.cpp"
#include "Libraries/ArduinoJson/ArduinoJson.h"
#include "Libraries/TimerThree/TimerThree.cpp"
#include "Libraries/Thermistor/Thermistor.cpp"

// ------------------------------------------------------------------------------------------
// VERSÃO DO FIRMWARE DO SISTEMA - ENSABrewControl
// ------------------------------------------------------------------------------------------

#define SISTEMA F(" ENSABrewControl")
#define VERSAO  F("  ver 1.0.00    ")

#define ERASE_EEPROM_USER        0        // 1 = Clear ALL EEPROM - USER
#define ERASE_EEPROM_CONFIG      0        // 1 = Clear ALL EEPROM - CONFIG

#define DEBUG_SERIAL             1        // 1 = Habilita o DEBUG pela Serial0
#define DEBUG_SOCKET             0        // 1 = Habilita o DEBUG pelo Socket (ETH0)

#define RESET                    0        // definição de RESET

// ------------------------------------------------------------------------------------------
// DEFINIÇÕESS DOS PINOS DO MICROCONTROLADOR - ATMEGA 2561
// ------------------------------------------------------------------------------------------

#define PINO_TERMISTOR           1        // Pino onde o Termistor NTC 10k deve ser conectado - PINOS 2 e 5 (cabo ENSABrew)
#define PINO_TECLADO             0        // Pino onde o KeyPad estão conectado - AD(0)
#define PINO_SSR                 5        // Pino de acionamento aquecedor (SSR) - HIGH -> ACENDE, LOW -> DESLIGA
#define PINO_RELAY1              22       // Pino Relé - LOW -> DESLIGA, HIGH -> ACENDE
#define PINO_SOLENOIDE1          34       // Pino Solenóide 1 - LOW -> DESLIGA, HIGH -> ACENDE
#define PINO_SOLENOIDE2          35       // Pino Solenóide 2 - LOW -> DESLIGA, HIGH -> ACENDE
#define PINO_NIVEL1              6        // Pino Sensor de Nível 1 - LOW -> DESLIGA, HIGH -> ACENDE
#define PINO_NIVEL2              7        // Pino Sensor de Nível 2 - LOW -> DESLIGA, HIGH -> ACENDE
#define PINO_FLUXO               19       // Pino Sensor Fluxo - INTERRUPÇÂO/INT1
#define PINO_AC                  18       // Pino de detecção de rede (AC) - INTERRUPÇÂO/INT0
#define PINO_BUZZER              4        // Pino do BUZZER/BEEP
#define LED_AMARELO              23       // Pino do LED AMARELO - HIGH -> ACENDE, LOW -> DESLIGA
#define LED_VERMELHO1            24       // Pino do LED VERMELHO 1 - HIGH -> ACENDE, LOW -> DESLIGA
#define LED_VERMELHO2            25       // Pino do LED VERMELHO 2 - HIGH -> ACENDE, LOW -> DESLIGA

// ------------------------------------------------------------------------------------------
// DEFINIÇÕES GERAIS DO MICROCONTROLADOR - ATMEGA 2561
// ------------------------------------------------------------------------------------------

// Se esta macro estiver definida, as funções do relógio estarão habilitadas
// #define FUNCTIONS_CLOCK   

#define AD_DEBOUNCE              5        // AD Debounce do teclado

#define BUZZER_GERAL             2        // Número de vezes que soará o BIP na INTRODUCAO do sistema
#define BUZZER_SALVAR            2        // Número de vezes que soará o BIP ao SALVAR
#define BUZZER_ERRO              2        // Número de vezes que soará o BIP no ERRO do sistema
#define BUZZER_ALARME            1        // Número de vezes que soará o BIP no ALARME do sistema
#define BUZZER_PATAMAR           1        // Número de vezes que soará o BIP na chegada do PATAMAR
#define BUZZER_MOSTURA           4        // Número de vezes que soará o BIP ao final da MOSTURA
#define BUZZER_ADICOES           2        // Número de vezes que soará o BIP nas ADIÇÕES
#define BUZZER_WHIRLPOOL         2        // Número de vezes que soará o BIP nos WHIRLPOOL
#define BUZZER_PERIODO           10       // Período do BUZZER da "mBUZZER"

#define DELAY_DEBOUNCE           5        // Delay Debounce do teclado
#define DELAY_EEPROM             5        // Delay Write/Read da EEPROM; Máximo de 3.3ms - DataSheet
#define DELAY_SALVAR             250      // Delay para SALVAR na EEPROM 
#define DELAY_GERAL              50       // Delay para tela GERAL
#define DELAY_ERRO               500      // Delay para tela de ERRO
#define DELAY_ALARME             500      // Delay para tela de ALARME

#define TIMER1                   1000     // TIMER1 (us) - 1ms - "globalInterruption();"
#define TIMER3                   3333     // TIMER3 (us) - 3,3ms/300Hz - "PMW - SSR". Em "ENSABrewENSAv10.4" o TIMER3 = 1000000
#define TIMER4                   10000    // TIMER4 (us) - 10ms - "machineBuzzer();"

#define AMOSTRAS_TECLADO         4        // Número de amostras do AD do teclado
#define MAX_AD_TECLADO           1010     // Valor máximo do AD para considerar "tecla solta"
#define BOUNCE_AD                5        // Número de bounce do AD do teclado
#define BOUNCE_UP                30       // Número de bounce do teclado (antes da leitura)
#define F_TONE                   3500     // Frequencia do BUZZER
#define TEMPO_ALARME             2000     // Tempo (ms) de impressão das mensagens de alarme - LCD
#define TEMPO_CONF               1000     // Tempo (ms) de impressão das mensagens de configuração - LCD
#define TEMPO_PWM                180      // Tempo (ms) para aguardar o PWM atingir o PATAMAR

#define RAMPA                    1        // RAMPA "statusFase" - pré-fervura
#define PATAMAR                  2        // PATAMAR "statusFase" - pré-fervura
#define FINAL                    3        // FINAL do processo "statusFase" - pós-fervura

#define KEY_RIGHT                0        // Tecla pra DIREITA
#define KEY_UP                   1        // Tecla pra CIMA
#define KEY_DOWN                 2        // Tecla pra BAIXO
#define KEY_LEFT                 3        // Tecla pra ESQUERDA
#define KEY_SELECT               4        // Tecla ENTER para confirmação
#define KEY_ESC                  5        // Tecla para SAIR
#define KEY_NONE                 6        // Sem tecla Pressionada

// #define V_KEY_UP                 F("UP")     // Tecla VIRTUAL pra CIMA
// #define V_KEY_DOWN               F("DOWN")   // Tecla VIRTUAL pra BAIXO
// #define V_KEY_RIGHT              F("RIGHT")  // Tecla VIRTUAL pra DIREITA
// #define V_KEY_LEFT               F("LEFT")   // Tecla VIRTUAL pra ESQUERDA
// #define V_KEY_SELECT             F("ENTER")  // Tecla VIRTUAL ENTER para confirmação
// #define V_KEY_ESC                F("ESC")    // Tecla VIRTUAL para SAIR

#define MIN_PATAMAR              1        // Mínimo número de PATAMARES desejado
#define MIN_TEMPERATURA_PATAMAR  1        // Temperatura máxima desejada no PATAMAR
#define MIN_MINUTO_PATAMAR       1        // Tempo mínimo desejado no PATAMAR

#define DEFAULT_MINUTO_PATAMAR   5        // DEFAULT MINUTO PATAMAR
#define DEFAULT_QT_PATAMAR       2        // DEFAULT QT PATAMAR
#define DEFAULT_TEMP_PATAMAR     25       // DEFAULT TEMPERATURA PATAMAR

#define MAX_PATAMAR              30       // máximo número de PATAMARES desejado
#define MAX_TEMPERATURA_PATAMAR  255      // Temperatura máxima desejada no PATAMAR
#define MAX_MINUTO_PATAMAR       300      // Tempo máximo desejado no PATAMAR

#define MIN_OFFSET_TEMP			 -10
#define MAX_OFFSET_TEMP			 10

#define MIN_HISTERESE_FACTOR	 0// -5
#define MAX_HISTERESE_FACTOR	 5

#define MAX_PWM                  100      // PWM máximo (em percentual)

#define MAX_LITROS				 999	  // Quantidade máxima de litros
#define MAX_CAL_FACTOR			 10	      // Valor máxim do fator de calibração

#define DEFAULT_MAX_PATAMAR      30        // máximo número default de PATAMARES desejado
#define DEFAULT_GRAU_MINUTO      1        // grau por minuto desejado
#define DEFAULT_PWM              95       // PWM default em percentual
#define DEFAULT_FERVURA          95       // Temperatura limite para iniciar tempo fervura

#define MAX_RECEITA              10        // MAXIMA RECEITA
#define MAX_NOME                 12       // MAXIMO NOMES (receita = 12)
#define MAX_ALFABETO             36       // MAXIMA letras do alfabeto
#define MAX_NUMEROS              10       // MAXIMA números

#define END_CONFIG               3800     // Endereço máximo da memória

#define _CRIAR_RECEITA           0		  // Sinaliza criação de receita
#define _EDITAR_RECEITA			 1		  // Sinaliza edição de receita

#define ST_RESP_NAO				 F("Nao") // Resposta: NÃO
#define ST_RESP_SIM				 F("Sim") // Resposta: SIM

#define ADDRESS_DS1307           0x68     // Endereço do RTC
#define NETEEPROM_END            115      // END address EEPROM configuration Bootloader - 
										  // 114 bytes USED (AVR Etherboot Open Escape Control v1.4)

#define SERVER_PORT              5000     // Porta de conexão TCP/IP - Server ENSA Tecnologia
#define ETH_CS                   10       // Select the Ethernet Module.
#define SD_CS                    4        // De-Select the internal SD Card
#define TIMEOUT_SOCKET           3        // Timeout connection socketENSA 
#define SERIAL_BAUD_RATE         115200   // Baud Rate Serial (DEBUG) e Serial1 (Bluetooth)
#define DATA_UTIL_SERIAL         512      // Tamanho máximo do array "DATA_UTIL_SERIAL"

// Máxima amostra de temperatura - Valores: (68, 75 ou 80)
#define MAX_SAMPLE_TEMPERATURE   1000       
// Quantidade default de amostras
#define DEFAULT_SAMPLE_TEMP		 (MAX_SAMPLE_TEMPERATURE / 2)


#define TIME_READ_TEMPERATURE    2 // 10		  // (*50ms)
#define TIME_SEND_TEMPERATURE 	 15       // (*1sec), se definir como 0, nunca enviará

#define INIT_TIME_INCREMENT 	 15 // 25 15  // *50ms

#define INTERNAL                 false    // Comandos internos do dispositivo
#define REMOTE                   true     // Comandos remotos

#define _AUTO_ADJUSTMENT 		 0		  // Sinaliza ajuste automático do fator de calibração
#define _MANUAL_ADJUSTMENT  	 1		  // Sinaliza ajuste manual do fator de calibração

#define ARDUINOJSON_ENABLE_PROGMEM    1   // Enable "ARDUINOJSON_ENABLE_PROGMEM"

#define DEFAULT_ID_MODULE		 F("1020ABC01") // Número de série/id padrão

#define _CONFIG_MENU			 0 // Sinaliza configuração por MENU
#define _CONFIG_SOCKET			 1 // Sinaliza configuração por SOCKET

#define _DISABLE				 0 // Sinaliza algo desabilitado
#define _ENABLE				 	 1 // Sinaliza algo habilitado

// Passos da BRASSAGEM:
enum passosBrassagem
{
	_STOP = 0,		// 0 = Parada
	_PRODUCAO,		// 1 = Em produção	 	 		 	 	
};

// ------------------------------------------------------------------------------------------
// PASSOS DA MAQUINA DE ESTADOS - FUNÇÕES E DISPLAY
// ------------------------------------------------------------------------------------------

enum passosMaquina
{
	mVERSAO = 0          	 ,	  	// Passo inicial: mostra VERSAO do SISTEMA
	mSTANDBY             	 ,      // Passo TELA BOAS VINDAS da máquina de estado
	
	mMENU                	 ,      // Passo MENU da máquina de estado
	
	mRECEITAS            	 ,      // Passo MENU DE RECEITAS da máquina de estado
	mRECEITASEL          	 ,      // Passo RECEITA SELECIONADA da máquina de estado
	mAPAGA_RECEITA       	 ,      // Passo APAGA RECEITA SELECIONADA da máquina de estado
	mSTART_PRODUCTION    	 ,      // Passo CONTINUA PRODUCAO da máquina de estado
	mVISUALIZA_RECEITA   	 ,	  	// Passo VISUALIZA RECEITA da máquina de estado
	
	mEXECUTA_PRODUCAO    	 ,      // Passo EXECUTA PRODUCAO da máquina de estado
	mLOOP_BRASSAGEM      	 ,      // Passo FASE BRASSAGEM da máquina de estado
	
	mCRIAR_RECEITA       	 ,      // Passo CRIAR RECEITA da máquina de estado
	mNOME_RECEITA        	 ,      // Passo MANTEM RECEITA da máquina de estado
	mQT_PATAMAR          	 ,      // Passo ENTRADA STRING da máquina de estado
	mTEMPMAX_PATAMAR     	 ,      // Passo TEMPERATURA MAXIMA PATAMAR da máquina de estado
	mMINUTO_PATAMAR      	 ,      // Passo MINUTO PATAMAR PATAMAR da máquina de estado

	mSALVA_RECEITA       	 ,      // Passo SALVA RECEITA da máquina de estado
	
	mADICIONAR_AGUA      	 ,      // Passo ADICIONAR AGUA da máquina de estado
	mCALCULA_FLUXO       	 ,      // Passo CALCULA FLUXO da máquina de estado
	
	mMENU_CONFIGURACAO   	 ,      // Passo MENU CONFIGURACAO da máquina de estado

	mSET_MAX_PATAMAR     	 ,      // Passo SET MAX PATAMAR da máquina de estado
	mSET_OFFSET_TEMP		 ,
	mSET_HISTERESE_FACTOR    ,
	mSET_GRAU_MINUTO     	 ,      // Passo SET GRAU POR MINUTO da máquina de estado
	mSET_PWM_SETPOINT    	 ,      // Passo SET PWM SETPOINT da máquina de estado
	mSET_DATA_HORA       	 ,      // Passo SET DATA HORA da máquina de estado
	mSET_SAMPLE_TEMP     	 ,      // Passo mSET_SAMPLE_TEMP da máquina de estado
	
	mMENU_TEMPO_ENVIO    	 ,      // Passo mMENU_TEMPO_ENVIO da máquina de estado
	mSET_SEND_TIME_AC    	 ,      // Passo SET_SEND_TIME_AC da máquina de estado
	mSET_SEND_TIME_TEMP  	 ,      // Passo SET_SEND_TIME_TEMP da máquina de estado

	mMENU_CAL_FACTOR     	 ,      // Passo MENU_CAL_FACTOR da máquina de estado
	mAUTO_CAL_FACTOR     	 ,      // Passo AUTO_CAL_FACTOR da máquina de estado
	mMANUAL_CAL_FACTOR   	 ,      // Passo MANUAL_CAL_FACTOR da máquina de estado
	
	mMENU_CONFIG_PID     	 ,	    // Passo mMENU_CONFIG_PID da máquina de estado
	mSTATUS_PID		     	 ,      // Passo mSTATUS_PID da máquina de estado
	mCONFIG_KP_PID	     	 ,      // Passo mCONFIG_KI_PID da máquina de estado
	mCONFIG_KI_PID	     	 ,      // Passo mCONFIG_KI_PID da máquina de estado
	mCONFIG_KD_PID	     	 ,      // Passo mCONFIG_KI_PID da máquina de estado

	mLIMPA_EEPROM      	     ,      // Passo LIMPA_EEPROM da máquina de estado
};

// ------------------------------------------------------------------------------------------
// PASSOS DA MAQUINA DE ESTADOS - BUZZER
// ------------------------------------------------------------------------------------------

#define gmBUZZER_OFF            0         // Passo BUZZER OFF da máquina de estado do buzzer
#define gmBIP_GLOBAL            1         // Passo BIP GLOBAL da máquina de estado do buzzer
#define gmBIP_ALARME            2         // Passo BIP ALARME da máquina de estado do buzzer

// ------------------------------------------------------------------------------------------
// DEFINIÇÕES DAS VARIÁVEIS GLOBAIS
// ------------------------------------------------------------------------------------------

#ifdef PROGMEM

// ----------------------------------------------------------------------- //
// Máquinas de estado

boolean _atendeMaquina;
boolean _atendeDisplay;
boolean _atendeBuzzer;

volatile uint8_t passoMaquina;
volatile uint8_t passoDisplay;
volatile uint8_t passoBuzzer;
uint8_t passoAnterior;

// ----------------------------------------------------------------------- //
// KeyPad

uint8_t bounceUP;
uint8_t countADTeclado = 0;
uint8_t bounceADTeclado = 0;
unsigned long ADTeclado = 0;
unsigned long ADTecladoAux = 0;
unsigned long CopyADTecladoAux = 0;

boolean _KEY_RIGHT;
boolean _KEY_UP;
boolean _KEY_DOWN;
boolean _KEY_LEFT;
boolean _KEY_SELECT;
boolean _KEY_ESC;
boolean _KEY_NONE;

boolean _keyTask;
boolean _keyPress;
boolean _atendeTeclado;

boolean _flagCheckIncrement = false;
boolean _flagWdtIncrement = false;

uint8_t timeWdtIncrement = 0;
uint8_t wdtIncrement = 0; 

// ----------------------------------------------------------------------- //
// Buzzer

uint8_t nBips;
uint8_t timerBuzzer;
uint8_t periodoBuzzer;

// ----------------------------------------------------------------------- //
// Entrada de dados

boolean _endString = false;
boolean _endInteger = false;
boolean _endValue = false;
boolean _digitarString = false;
boolean _digitarInteger = false;
boolean _digitarValue = false;

int8_t numLetra = -1;
String stDigitado;
String stChar = "_";
float valorDigitado = 0;

// ----------------------------------------------------------------------- //
// Receitas

int ind = 0;
int qtde;
int qtdeMin;
boolean prOper;

boolean _contaTempo = false;

byte numPatamar;
byte qtdePatamar;
int tempoInicial;
int tempoProximo;

byte statusFase;

uint8_t valorPwm = MAX_PWM;
uint8_t valorPwmManual;
int valorTempoManual = 0;

int tempInicialAquecimento = -1000;

int idReceitaSel;
float speedAquecimento = 0;

boolean _temperaturaMaxEntrou = false;
String stResp = "_";

boolean _loadTimerPwm = false;

int tempoInicialVelocidade = 0;
float grauPorMinuto = 0;
float temperaturaFloatInicial = 0;

int tempoRestante = 0;

// ----------------------------------------------------------------------- //
// SetPoint

// boolean _waitWarm = false;
// Tempo de controle do SetPoint - 1 minuto
#define TIME_SET_POINT_RISE		60
// Temporizador de subida do setPoint
uint8_t wtdRiseSetPoint = 0;
// Controle da temperatura do SetPoint
float actualTempSetPoint = 0;

// ----------------------------------------------------------------------- //
// Temporizadores

#define TIMER_50ms		50 // (*1ms)
#define TIMER_1000ms	20 // (*50ms)
#define TIMER_3000ms	3  // (*1000ms)

uint8_t wdt50ms = TIMER_50ms;
uint8_t wdt1000ms = TIMER_1000ms;
uint8_t wdt3000ms = TIMER_3000ms;

uint8_t wdtDadosBrassagem;
uint8_t wdtTimesTemperatura = TIME_READ_TEMPERATURE;

int wdtTimesDisplay;
int wdtTimesBlink;
long wdtPwmFull;

uint8_t wdtSendTemp;

#define TIME_SEND_READ_AC		1 // (*1sec)
uint8_t wdtSendReadAC;

boolean _flag50ms;
boolean _flag1000ms;
boolean _flag3000ms;
boolean _pwmFull;
boolean _sendDataApp;

boolean _msgConvite;
boolean _msgENSABrew;
boolean _msgTemperatura;

// ----------------------------------------------------------------------- //
// Controle e gerenciamento da comunicação - APP

enum auxTypeHeader
{
	_HEADER_SET = 0,
	_HEADER_GET,
	_HEADER_EVENT,
	_HEADER_SCREEN,
};

enum auxTypeCommand
{
	_CONNECTION_APP = 1,
	_TEMPERATURE,
	_READ_AC,
	_READ_PORT,
	_COUNT_FLUX,
	
	_LOOP_PATAMARES,

	_GET_ID,
	_GET_CONFIG,
	_GET_CAL_FACTOR,
	_GET_CONFIG_PID,
	_GET_SEND_TIME_AC,
	_GET_SEND_TIME_TEMP,

	_SET_RESPONSE,
};
	
// Sinaliza o status da conexão com o APP
boolean _connectedAPP = true;

// Flag de controle de envio do keep alive 
boolean _flagSendKeepAlive = false;

// Temporizador de envio do keep alive
#define TIME_SEND_KEEP_ALIVE		5 // (*1sec)
uint8_t wdtSendKeepAlive = TIME_SEND_KEEP_ALIVE;

// Flag de controle de aguardo de resposta do keep alive 
// boolean _flagWaitRespKeepAlive = false;

// Temporizador de aguardo de resposta do keep alive
#define TIME_WAIT_RESP_KEEP_ALIVE	10 // (*1sec)
uint8_t wdtWaitRespKeepAlive = 0;

enum auxGeneralCommands
{
	_LOAD = 0,
	_CLEAR,
	_SEND,
	_LOAD_WAIT,
};

// ----------------------------------------------------------------------- //
// Leitura AC

boolean _faltouAC = false;
boolean _sendDataAC = false;
volatile byte pulseAC = 0;
volatile byte Npulse = 0;

// ----------------------------------------------------------------------- //
// Contagem de volume 

float volumeDigitado;
float flow = 0.0;
float milli = 0.0;
float liters = 0.0;
float alarmNivel = 0;

uint8_t wdtResetFluxo;
boolean _flagResetFluxo;
boolean _auxAdjustCalFactor;
boolean _stopCountFlux = false;

// ----------------------------------------------------------------------- //
// Leitura da temperatura

boolean _readTemperature = false;
// unsigned int countTemperature = 0;
// float realTemperature = 0;
uint16_t tempFilter[MAX_SAMPLE_TEMPERATURE];
double mediaTemperature = 0;

Thermistor thermistor(PINO_TERMISTOR);

// ----------------------------------------------------------------------- //
// Serial

boolean _newDataSerial = false;
char receivedSerial[DATA_UTIL_SERIAL];

static boolean _recvInProgress = false;
static uint8_t idx = 0;
volatile char dataChar;

// ----------------------------------------------------------------------- //
// Leitura dos ports - pinos 6 e 7

boolean statePort_1;
boolean lastStatePort_1;
uint16_t lastDebounceTimePort_1;

boolean statePort_2;
boolean lastStatePort_2;
uint16_t lastDebounceTimePort_2;

uint8_t debounceDelay = 100;

//boolean _auxStatePort_1;
//boolean _auxStatePort_2;

// ----------------------------------------------------------------------- //
// Acionamento solenóides

#define SOLENOID1				0
#define SOLENOID2				1

#define TIMER_IN_MILISECONDS	0
#define TIMER_IN_SECONDS 		1
#define TIMER_IN_MINUTES 		2
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
void loop() 
{
  if (_flagCheckIncrement && !_keyPress) 
  	checkIncrement();

  keyPad();

  stateMachine();
  machineDisplay();

  serialReceiver();
  // analyzesDataSerial();

  controlTemperatureTasks();
  
  if(configGeral.timeSendReadAC != 0)
  	readAC();
  
  readPortTasks();

  communicationAPPTasks();
}

// =================================================================================( * FIM * )
// =======================================================================( * FIM * )
// =============================================================( * FIM * )
// ===================================================( * FIM * )
// =========================================( * FIM * )
// ===============================( * FIM * )
// =====================( * FIM * )
// ===========( * FIM * )
// =( * FIM * )

// =================================================================================( * FIM * )
// =======================================================================( * FIM * )
// =============================================================( * FIM * )
// ===================================================( * FIM * )
// =========================================( * FIM * )
// ===============================( * FIM * )
// =====================( * FIM * )
// ===========( * FIM * )
// =( * FIM * )

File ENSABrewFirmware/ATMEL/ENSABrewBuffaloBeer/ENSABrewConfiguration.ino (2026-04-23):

//*******************************************************************************************
// Arquivo C/C++ do Projeto Controlador de Patamares -- ENSABrewControll
//-------------------------------------------------------------------------------------------
//
// Arquivo: ENSABrewConfiguration.ino
//
// Autor  : Cláudio B. Pimenta, A.S
// Autor  : Jânio Anselmo, Eng. Me.
// Autor  : Thiago Anselmo, Tecgº
// Autor  : Gabriel da Silva Caetano
//
// CPU    : ATMega2561 - MegaCore
// Clock  : 16MHz
//
//*******************************************************************************************


//WWWWWWWWWW*********************************************************************************
// Função: configSendTimeAC
// Data  : 13/12/2019 13:45
//WWWWWWWWWW*********************************************************************************

void configSendTimeAC(void )
{
	if (_keyPress && (_KEY_LEFT || _KEY_ESC)) 
    {
    	// Reseta a entrada de dados
       	resetDataInput(false);
       	// Altera o passo da máquina
       	passoMaquina = mMENU_TEMPO_ENVIO;
       	// Retorna
       	return;
    }
    	
    // Digita o valor à ser configurado
    entradaValorGeral(configGeral.timeSendReadAC, 0, 255, false);

    // Se finalizou a configuração
    if (_endValue) 
    {
    	// Reseta a entrada de dados
		resetDataInput(false);
        // Configura o valor em questão
        configGeral.timeSendReadAC = valorDigitado;
        // Salva a configuração
        salvaConfigGeral(_CONFIG_MENU);
        // Altera o passo da máquina
        passoMaquina = mMENU_TEMPO_ENVIO;
        // Retorna
        return;
    }
}

//WWWWWWWWWW*********************************************************************************
// Função: configSendTimeTemperature
// Data  : 13/12/2019 13:45
//WWWWWWWWWW*********************************************************************************

void configSendTimeTemperature(void )
{
	if (_keyPress && (_KEY_LEFT || _KEY_ESC)) 
    {  
    	// Reseta a entrada de dados
		resetDataInput(false);
		// Altera o passo da máquina
		passoMaquina = mMENU_TEMPO_ENVIO;
		// Retorna
		return;
    }
    	
    // Digita o valor à ser configurado
    entradaValorGeral(configGeral.timeSendTemp, 0, 255, false);

    // Se finalizou a configuração
    if (_endValue) 
    {
    	// Reseta a entrada de dados
		resetDataInput(false);
        // Configura o valor em questão
        configGeral.timeSendTemp = valorDigitado;
        // Salva a configuração
        salvaConfigGeral(_CONFIG_MENU);
        // Altera o passo da máquina
        passoMaquina = mMENU_TEMPO_ENVIO;
        // Retorna
        return;
    }
}
   	
//WWWWWWWWWW*********************************************************************************
// Função: configMaxPatamares
// Data  : 13/12/2019 13:50
//WWWWWWWWWW*********************************************************************************

void configMaxPatamares(void )
{
	if (_keyPress && (_KEY_LEFT || _KEY_ESC)) 
    {
    	// Reseta a entrada de dados
		resetDataInput(false);
		// Altera o passo da máquina
		passoMaquina = mMENU_CONFIGURACAO;
		// Retorna
		return;
    }

    // Digita o valor à ser configurado
    entradaValorGeral(configGeral.qtdeMaxPatamar, 1, MAX_PATAMAR, false);

    // Se finalizou a configuração
    if (_endValue) 
    {
    	// Reseta a entrada de dados
		resetDataInput(false);
		// Configura o valor em questão
		configGeral.qtdeMaxPatamar = valorDigitado;
		// Salva a configuração
		salvaConfigGeral(_CONFIG_MENU);
		// Altera o passo da máquina
		passoMaquina = mMENU_CONFIGURACAO;
		// Retorna
		return;
    }
}

//WWWWWWWWWW*********************************************************************************
// Function: configOffSet
// Date    : 30/05/2020 - 15:15
//WWWWWWWWWW*********************************************************************************

void configOffSet(void )
{
  	if (_keyPress && (_KEY_LEFT || _KEY_ESC)) 
    {
    	// Reseta a entrada de dados
		resetDataInput(false);
		// Altera o passo da máquina
		passoMaquina = mMENU_CONFIGURACAO;
		// Retorna
		return;
    }

    if(!_endValue)
    {
    	float auxOffSet = CONV_OFFSET_TEMP_FLOAT(configGeral.offSetTemp);
		entradaValorGeral(auxOffSet, MIN_OFFSET_TEMP, MAX_OFFSET_TEMP, true);
    }

    // Se finalizou a configuração
    if (_endValue) 
    {
    	// Reseta a entrada de dados
		resetDataInput(false);
		// Configura o valor em questão
		configGeral.offSetTemp = CONV_OFFSET_TEMP_INT(valorDigitado);
		// Salva a configuração
		salvaConfigGeral(_CONFIG_MENU);
		// Altera o passo da máquina
		passoMaquina = mMENU_CONFIGURACAO;
		// Retorna
		return;
    }
}

//WWWWWWWWWW*********************************************************************************
// Function: configHistereseFactor
// Date    : 30/05/2020 - 15:15
//WWWWWWWWWW*********************************************************************************
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

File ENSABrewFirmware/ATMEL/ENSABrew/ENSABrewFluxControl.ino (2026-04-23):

//*******************************************************************************************
// Arquivo C/C++ do Projeto Controlador de Patamares -- ENSABrewControll
//-------------------------------------------------------------------------------------------
//
// Arquivo: ENSABrewFluxControl.ino
//
// Autor  : Cláudio B. Pimenta, A.S
// Autor  : Jânio Anselmo, Eng. Me.
// Autor  : Thiago Anselmo, Tecgº
// Autor  : Gabriel da Silva Caetano
//
// CPU    : ATMega2561 - MegaCore
// Clock  : 16MHz
//
//*******************************************************************************************

//WWWWWWWWWW*********************************************************************************
// Função: adicionarAgua
// Data  : 04/04/2017 13:45
//WWWWWWWWWW*********************************************************************************

void adicionarAgua(void ) 
{
  // Sinaliza contagem do fluxo habilitada
  _stopCountFlux = false;

  if (_keyPress && (_KEY_LEFT || _KEY_ESC)) 
  {
    // Reseta a entrada de dados
    resetDataInput(false);

    // Se é calibração
    if(_auxAdjustCalFactor) 
    {
      // Limpa a flag de sinalização de calibração
      _auxAdjustCalFactor = false;
      // Cálcula o fator automaticamente
      passoMaquina = mMENU_CAL_FACTOR;
      // Retorna
      return;
    }
    else { passoMaquina = mMENU; return; }
  }

  // Se for calibração
  if(_auxAdjustCalFactor)
    entradaValorGeral(5, 1, 10, true);
  else 
    entradaValorGeral(30, 1, MAX_LITROS, true);
  if (_endValue) 
  {
    _endValue = false;
    volumeDigitado = valorDigitado;
    digitalWrite(PINO_RELAY1, HIGH);
    
    wdtResetFluxo = 0;
    _flagResetFluxo = false;
    
    passoMaquina = mCALCULA_FLUXO;
  }
}

//WWWWWWWWWW*********************************************************************************
// Função: callPulse - Interruption INT SENSOR FLOW
// Data  : 09/09/2016 09:55
// Revisão  :
//WWWWWWWWWW*********************************************************************************

void callPulse(void ) 
{
  Npulse++;
}

//WWWWWWWWWW*********************************************************************************
// Função: calculaFluxo - Calcula o fluxo e volume de entrada
// Data  : 09/09/2016 09:55
// Revisão  :
//WWWWWWWWWW*********************************************************************************

void calculaFluxo(float alarmNivel) 
{
  if (_keyPress) 
  {
    if (_KEY_ESC) 
    {
      // Carrega os 5 segundos para zerar o fluxo
      if(wdtResetFluxo == 0 && !_flagResetFluxo) 
      {
        wdtResetFluxo = 5;
        _flagResetFluxo = true;
      }
    }
    else if (_KEY_SELECT) 
    {
      if(_auxAdjustCalFactor) 
      {
        // Desatraca o relé
        digitalWrite(PINO_RELAY1, LOW);
        // Limpa a flag de sinalização de calibração
        _auxAdjustCalFactor = false;
        // Cálcula o fator automaticamente
        passoMaquina = mAUTO_CAL_FACTOR;
          return;
      }
      // Se não for calibração, simplesmente para a contagem
      else {
        Npulse = 0;
        _stopCountFlux = !_stopCountFlux;
        digitalWrite(PINO_RELAY1, !_stopCountFlux);  
      }
    }
  }
  else if(_flagResetFluxo) 
  {
    uint8_t auxReadADC = analogRead(PINO_TECLADO);
    
    /*
      Verifica se o botão ESC não está pressionado, se já soltou,
      volta para o menu, se não, continua contando para zerar
    */

    if(auxReadADC > 50) 
    {
      wdtResetFluxo = 0;
      _flagResetFluxo = false;
      digitalWrite(PINO_RELAY1, LOW);
      
      // Se é calibração
      if(_auxAdjustCalFactor) 
      {
        // Limpa a flag de sinalização de calibração
        _auxAdjustCalFactor = false;
        // Cálcula o fator automaticamente
        passoMaquina = mMENU_CAL_FACTOR;
      }
      else passoMaquina = mMENU;
      return;
    }
  }

  else if (_flag1000ms && !_stopCountFlux) 
  {
    _flag1000ms = false;
    detachInterrupt(digitalPinToInterrupt(PINO_FLUXO));
    flow = (Npulse / configGeral.calFactor);
    milli = (flow / 60);
    liters = liters + milli;
    Npulse = 0;
    attachInterrupt(digitalPinToInterrupt(PINO_FLUXO), callPulse, RISING);
    if ((liters > 0) && (alarmNivel > 0)) 
    {
      if (liters >= alarmNivel) 
      {
        digitalWrite(PINO_RELAY1, LOW);

        // Se era calibração
        if(_auxAdjustCalFactor) 
        { 
          printDisplay(F(" Volume Inserido"), F("  Foi Atingido! "), TEMPO_CONF);
          // Limpa a flag de sinalização de calibração
          _auxAdjustCalFactor = false;
          // Cálcula o fator automaticamente
          passoMaquina = mAUTO_CAL_FACTOR;
          // Retorna
          return;
        }
        else if (_keyPress) 
        {
          if (_KEY_ESC) 
          { passoMaquina = mMENU; return; }
        }
        if (_flag3000ms)
          bipAlarme();
      }
    }

    // Envia os dados do fluxo
    if(_connectedAPP)
      sendDataFlux();
  }
}
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

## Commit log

2023-04-21 ENSABrew - Mechanical Project
    Uploading Mechanical Project V1 and V2
    [AdesivoConectores.DXF, DS1022-1x7RUF11.SLDPRT, DisplayLCD.SLDPRT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]
2023-04-21 Update Protocol, Polycarbonate, PCB and SCH files
    Update Protocol, Polycarbonate, PCB and SCH files
    [EZBrew-100A - BOM.xlsx, EZBrew-100A -SCH.sch]
2023-04-21 Update README.md
    How to install the board on the Arduino platform
2023-04-22 Update name file SCH
    Update name file SCH
    [EZBrew-100A - SCH.sch]
2023-04-23 Update Files Project
    Update Files Project
    [AdesivoConectores.DXF, DS1022-1x7RUF11.SLDPRT, DisplayLCD.SLDPRT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]
2026-04-20 Refine serial error handling and hex decode performance
    [ENSABrewFormatData.ino, ENSABrewSerial.ino]
2026-04-20 Polish serial parser control flow and avoid String churn
    [ENSABrewFormatData.ino, ENSABrewSerial.ino]
2026-04-20 Avoid long interrupt lock while receiving serial frames
    [ENSABrewSerial.ino]
2026-04-25 Apply audit safety fixes
    [ENSABrewSerial.ino]
2026-04-30 Fix serial interrupt handling
    [ENSABrewSerial.ino]
